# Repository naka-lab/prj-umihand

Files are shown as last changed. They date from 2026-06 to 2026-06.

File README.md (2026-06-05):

# prj-umihand
UMI Hand assembly guide and modified models for use in Japan.
# UMI Hand (Nakamura Lab Version)

This repository contains:

- Modified UMI Hand CAD models
- Parts list available in Japan
- Printing settings

## Directory Structure

models/
Modified CAD files

bom/
Parts list

images/
Assembly photos

docs/
Assembly guide

print_settings/
3D printing settings

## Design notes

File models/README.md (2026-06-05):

# Models

This directory contains modified CAD models for the UMI Hand.

## Background

The original UMI Hand design uses a linear rail that is not readily available in Japan. To enable assembly using components that can be purchased domestically, several CAD models were modified.

These modifications were created and validated at Nakamura Laboratory, The University of Electro-Communications.

## Modified Parts

### gripper-bottom_plate

Modified to match the dimensions and mounting-hole locations of the linear rail available in Japan.

### gripper-grip

Modified accordingly to maintain compatibility with the updated gripper-bottom_plate.

## File Types

### STEP Files (.step)

STEP files are provided for CAD editing and further design modifications. These files can be imported into CAD software such as Fusion 360, SolidWorks, and FreeCAD for customization and future development.

Examples:
- gripper-bottom_plate-v1.step
- gripper-grip-v1.step

### STL Files (.stl)

STL files are provided for direct 3D printing. These files can be imported into slicer software such as Bambu Studio, Cura, or PrusaSlicer without additional CAD processing.

Examples:
- gripper-bottom_plate.stl
- gripper-grip.stl

## Notes

- The remaining parts are identical to the original UMI Hand design.
- Please refer to the BOM directory for the corresponding parts list available in Japan.

## Revision History

### v1.0

- Adapted the design for a Japan-available linear rail.
- Updated:
  - gripper-bottom_plate
  - gripper-grip

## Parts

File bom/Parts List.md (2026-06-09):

# Parts List (Japan Version)

The following parts were used to assemble the modified UMI Hand at Nakamura Laboratory.

## Linear Rail

### MGN9C Linear Guide (MGN9C1R150Z0HM, MISUMI)

https://jp.misumi-ec.com/vona2/detail/221005481777/
- ブロック種類：標準タイプ
- レール種類：標準
- ブロック数：1
- レール寸法：9
- 組み立て寸法：10
- レール長さ：150

## Spring

### Compression Spring (UR10-50)

https://jp.misumi-ec.com/vona2/detail/110302604820/
- 自由長：50
- 外径：10
- 線形：0.8

## Notes

The primary difference from the official UMI Hand BOM is the linear rail system.

To accommodate components that are readily available in Japan, the following CAD files were modified:

- gripper-bottom_plate
- gripper-grip

All other components follow the original UMI Hand design.

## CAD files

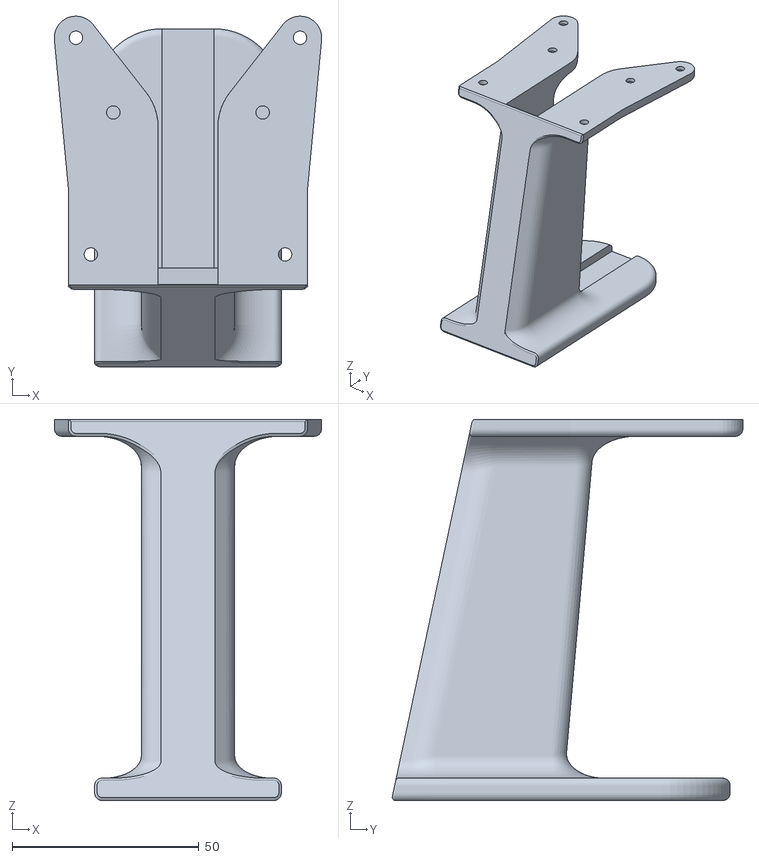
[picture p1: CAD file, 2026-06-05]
models/gripper - grip.stl
71.6 x 93.9 x 102.0

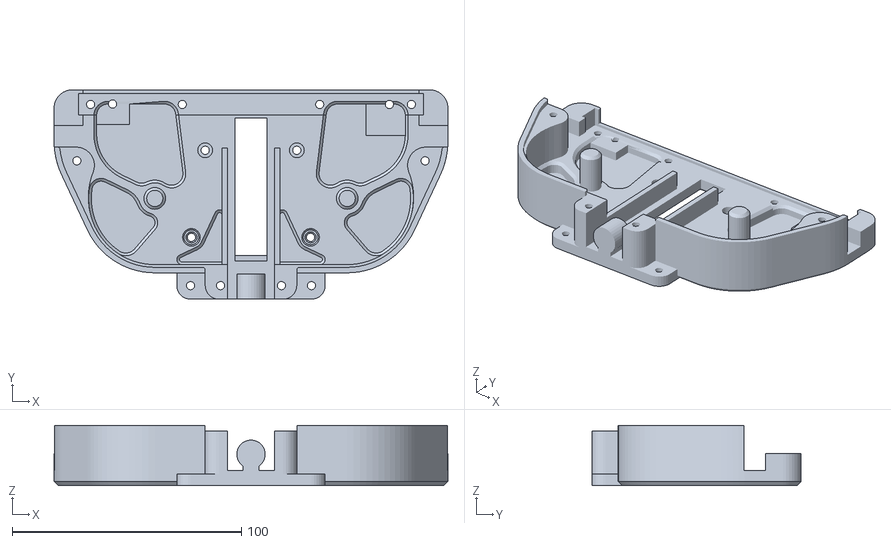
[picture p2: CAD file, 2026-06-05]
models/gripper - bottom_plate.stl
172.0 x 91.4 x 26.3

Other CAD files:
models/gripper - bottom_plate - v1.step
models/gripper - grip - v1.step

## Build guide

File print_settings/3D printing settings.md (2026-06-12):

# 3D Printing Settings

The following settings were used to print the modified UMI Hand components at Nakamura Laboratory.

## Tested Configuration

| Item | Value |
| --- | --- |
| Printer | Bambu Lab P2S |
| Nozzle | 0.4 mm |
| Rigid Material | Bambu PLA Basic |
| Flexible Material | Bambu TPU 95A |
| Last Tested | 2026-06-11 |

## PLA Settings for Rigid Components

The following settings were used for the modified rigid structural components.

| Parameter | Value |
| --- | --- |
| Layer Height | 0.20 mm |
| Initial Layer Height | 0.20 mm |
| Wall Loops | 3 |
| Top Shell Layers | 6 |
| Bottom Shell Layers  | 6 |
| Infill Density | 20% |
| Infill Pattern | Gyroid |
| Supports | Enabled where necessary |
| Build Plate Adhesion | Default |
| Nozzle Temperature | 200°C |
| Bed Temperature | 60°C |

## TPU Settings for Finger Pads

The following settings were used for the flexible finger pad components.

| Parameter | Value |
| --- | --- |
| Material | Bambu TPU 95A |
| Layer Height | 0.20 mm |
| Initial Layer Height  | 0.20 mm |
| Wall Loops | 4 |
| Top Shell Layers | 8 |
| Bottom Shell Layers | 8 |
| Sparse Infill Density | 95% |
| Sparse Infill Pattern | Lines |
| Nozzle Temperature | 250°C |
| Bed Temperature | 40°C |
| Cooling Fan | 0% |
| Auxiliary Fan | 0% |
| Outer Wall Speed | 20 mm/s |
| Inner Wall Speed | 25 mm/s |
| Infill Speed | 25 mm/s |
| Top Surface Speed | 20 mm/s |
| Initial Layer Speed | 15–20 mm/s |
| Supports | Avoid if possible |
| Brim | Recommended for small parts |

## Notes and Validation

* The modified PLA components were successfully printed and assembled into a functional UMI Hand.
* The flexible finger pad components were successfully printed using TPU 95A with a 0.4 mm nozzle on the Bambu Lab P2S.
* For TPU printing, it is recommended to dry the filament before printing and feed it directly from a dry box when possible.
* Total printing time for all modified PLA parts is less than 12 hours on the P2S.
* Users who intend to modify the material, nozzle diameter, or filament brand should perform additional validation regarding dimensional accuracy, assembly compatibility, and mechanical performance.

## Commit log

2026-06-05 Add README for modified CAD models of UMI Hand
2026-06-05 Add modified models
    [gripper - bottom_plate - v1.step, gripper - grip - v1.step]
2026-06-05 Add stl models used for 3D printing
    [gripper - bottom_plate.stl, gripper - grip.stl]
2026-06-05 Update README with file type information for CAD and 3D printing
    Added sections for STEP and STL file types with usage details.
2026-06-05 Create parts list for Japan version of UMI Hand
    Added a parts list for the Japan version of the UMI Hand, including details on linear rail and spring components.
2026-06-05 Add 3D printing settings documentation
    Documented 3D printing settings for UMI Hand components, including printer specifications and recommended parameters.
2026-06-09 Revise Parts List with new links and details
    Updated links and specifications for MGN9C Linear Guide and Compression Spring.
2026-06-12 Revise 3D printing settings and add detailed tables
    Updated 3D printing settings with detailed tables for both rigid and flexible components, including tested configurations and parameters for PLA and TPU materials.
